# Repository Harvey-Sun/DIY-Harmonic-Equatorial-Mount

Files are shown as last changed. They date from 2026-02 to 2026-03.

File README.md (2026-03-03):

# DIY谐波赤道仪（已通电验证，待实拍测试）

由于我厌倦了EQ3D赤道仪的沉重，我计划用更轻便的谐波赤道仪来替换它，然而市面上的谐波赤道仪价格太贵（与DIY的规格相比），所以这个项目就此诞生，谐波赤道仪能够在不牺牲性能的前提下，提供高精度、便携性和经济性

# 项目描述

自制谐波赤道仪的核心谐波减速器，是基于Leaderdriver拆机二手的工业谐波减速器(也适用于淘宝购买的同规格谐波减速器如“25-100”)
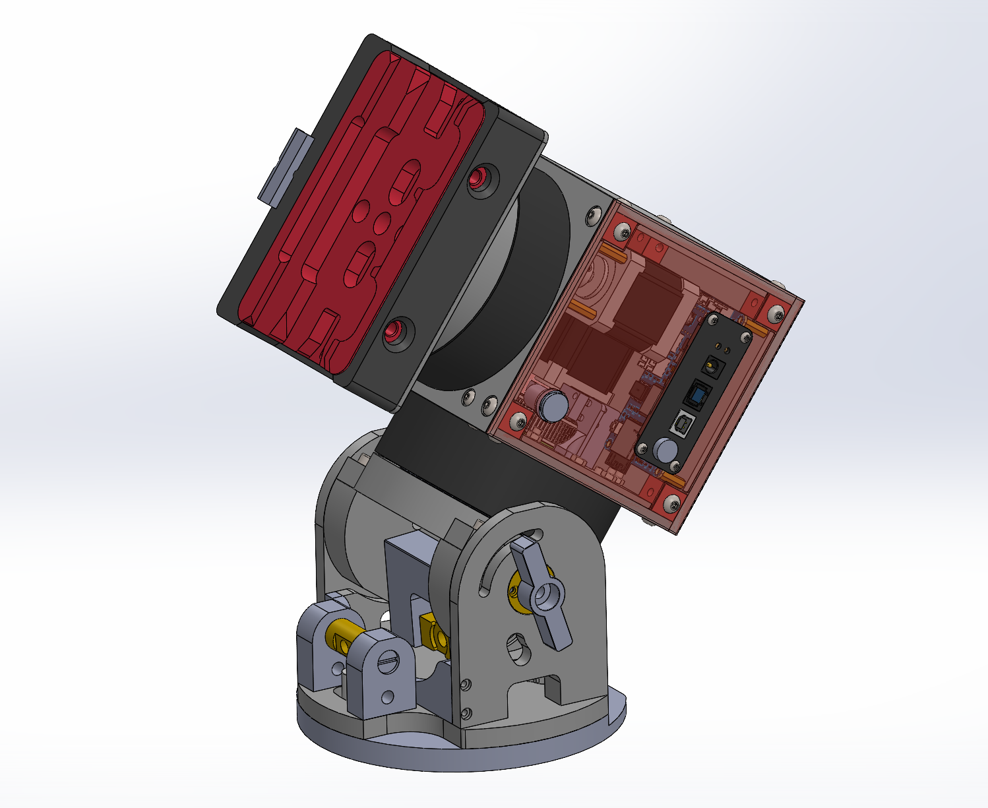
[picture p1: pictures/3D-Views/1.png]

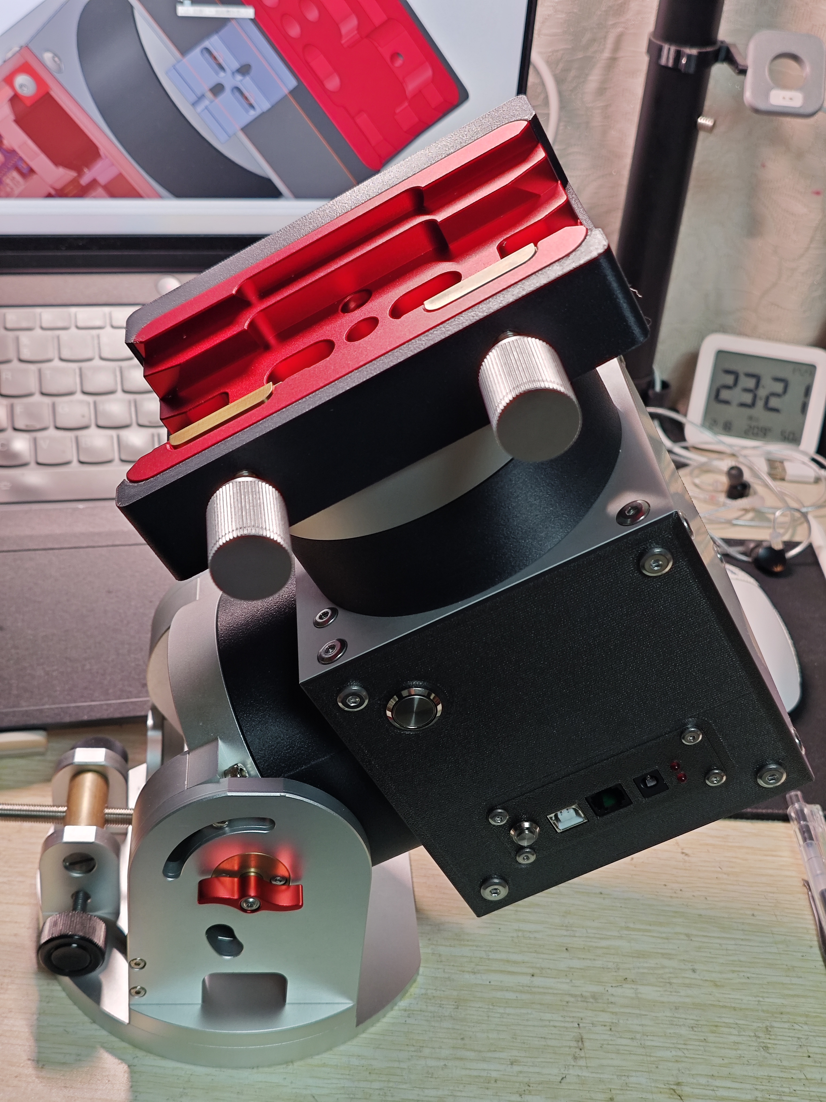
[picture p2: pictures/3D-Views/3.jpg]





该项目旨在解决业余天文设备中的关键问题：
- 成品支架价格高昂
- 缺乏开放性和灵活性
- 复杂性或与个人设置的不兼容

此款DIY谐波赤道仪优势是：
- 🧰**经济实惠**——总造价低于3000元，加工零件价格低于1500元
- 🪶**相对便携**——不含底座重量7.5公斤
- 🏗️**易于搭建**——专为拥有基本工具的创客设计
- 💪**高性能**——精确跟踪（亚角秒级 RMS），无需配重
- ⚠️**关于当前项目状态的说明**⚠️
该项目只完成了通电和简单的goto测试未进行实拍测试

# ✨主要特点
| **特征** | **描述** |
| :----- | :----- |
| 安装类型 | GEM德式赤道仪 |
| 传动类型 | 谐波减速器+皮带传动+42步进电机 |
| 有效载重 | 最大载重30kg(最好需要配重)，无需配重载重为20-25kg |
| 减速器类型 | leaderdrive LHS-25-100-C-III |
| 控制系统 | OnStep/OnStepx |
| 连接类型 | USB-B；WIFI；蓝牙；集成DS3231SN时钟芯片 |
| 硬件功能 | RA轴制动器；RA/DEC轴光电传感器限位；DEC/RA轴光电传感器原点；<br>同时兼容step/dir，spi两种驱动模式(即兼容tmc2209，tmc5160)；12/24v输入 |
| 预计成品 | 2200-2600 RMB |
| 预计重量 | 9.5kg(包含鸠尾槽和纬度座) |

## 🔗 物料清单 (BOM)

请参阅 [BOM.md](BOM.md)

**预计总成本：约2500RMB（含纬度座）**

本项目的主体结构高度依赖定制，主要部件包含两台 25-100 规格的谐波减速器，提供了极高的传动比与扭矩，底座接口可根据个人习惯适配主流的三脚架

*注：价格为近似值，可能因电机供应商、CNC 加工批次和地点而异*

---

## 🔌 电子部分概览

控制系统完全采用定制设计，并围绕紧凑结构构建，它包括：

* **基于 ESP32-WROOM-32E16N 的主控核心**，运行强大的 [OnStep/OnStepX](https://onstep.groups.io/g/main/wiki) 系统
* **搭配 ESP07S 无线连接**，提供高效的无线/有线通讯
* **TMC系列步进电机驱动器**，实现赤经与赤纬轴精确、静音的微步进控制与指向
* **高效电源管理方案**，板载 TPS5450 降压模块和 AMS1117 LDO 稳压芯片，确保高负载下系统电压的纯净与稳定
* 集成 **零位传感器和限位开关** 接口，在运行中保障设备的安全
* 支持通过 Wi-Fi、蓝牙或 USB 路由进行远程控制，无缝对接主流天文摄影软件生态 (N.I.N.A., INDI, ASCOM 等)
* 控制板在 PCB 走线设计上充分考虑了扩展性需求，通过主板驱动器插槽旁的排针跳线 (Jumpers)，您可以轻松地在先进的 **SPI 智能控制模式**和传统的 **STEP/DIR 独立模式**之间进行物理切换(切换后需刷写固件)

* **TMC5160 SPI 模式 (推荐配置) 🚀**
    * **硬件设置**：使用跳线帽闭合 SPI 专用的针脚组，将 ESP32 的 SPI 总线直接连接至 TMC5160 驱动器
    * **系统优势**：彻底告别手动调节电位器，允许 OnStep 固件直接读取和写入寄存器，您可以在 Web 界面或 `Config.h` 中实时配置运行/保持电流、精确设置细分数（Microstepping），并在 StealthChop（极致静音）和 SpreadCycle（高动态扭矩）模式之间智能切换，最大化释放谐波减速器的性能
    * **固件配合**：在 `Config.h` 中将赤经/赤纬驱动模型定义为 `TMC5160_SPI`

* **传统 STEP/DIR 模式 (向下兼容) 🔌**
    * **硬件设置**：断开 SPI 通讯跳线
    * **适用场景**：作为一种可靠的底层回退方案。如果您需要临时替换为普通的 A4988、DRV8825，或者仅使用 TMC 驱动器的 Standalone (独立运行) 模式，此设计提供了极大的硬件容错率和维修便利性
    * **固件配合**：需要在 `Config.h` 中精确填写您通过跳线帽设定的细分值，并**必须手动使用万用表和陶瓷螺丝刀**调节驱动器上的 VREF 电位器来设定电机电流

> 💡 **硬件设计提示**：为确保 SPI 高速通讯时的数据完整性，我们在定制 PCB 上对相关通讯走线进行了严格的间距控制
**警告：在插拔驱动器或更改跳线设置前，请务必完全断开系统主电源（包括 USB 供电），以防瞬间浪涌击穿 TMC5160 或 ESP32 主控**

所有电路板原理图及 PCB Layout（严格把控了安全间距、过孔尺寸和大电流线宽）均使用开源工具设计，您可以在 [https://member.jlc.com/?spm=PCB.Homepage] 订购 PCB或对其进行重新组合以满足您的需求

## 💻 固件配置与刷写

请参阅 [Firmware_Setup.md](https://github.com/LeoJohn233/DIY-Harmonic-Equatorial-Mount/blob/main/software/Firmware_Setup.md) 获取完整的 `Config.h` 参数表及详细引脚映射

谐波赤道仪的主控搭载了 **ESP32-WROOM-32E (16MB)，ESP**，这款大容量核心不仅能轻松运行复杂的 [OnStep / OnStepX](https://onstep.groups.io/g/main/wiki) 固件，还为内置星表、高精度对位模型 (Pointing Model) 以及功能丰富的 Smart Web UI 留出了充足的存储空间

---

## 🛠️ 机械部分组装指南

请参阅 [Assembly.md](Assembly.md)

下图显示了构建 Dual 25 所需的全部机械和电子零件

*(请在此处插入您在“新年首发”时拍摄的组装完成图或零配件合影)*

每个组件都经过精心挑选或设计，以确保高机械精度和易于组装。从 CNC 加工的坚固铝制主体、25-100 谐波减速器，到步进电机和控制器的 3D 打印防护外壳，每一步都经过了严格的测试与指向模型校准。

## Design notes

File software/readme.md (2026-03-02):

# OnStep 优化补丁 (For N.I.N.A. & APP)

## 📌 背景与痛点

在使用 OnStep 驱动谐波赤道仪时，由于谐波减速器不具备物理离合、静摩擦力小且扭矩极大，如果在开机未回零（未建立绝对坐标）的情况下误触指令，或设备两端不平衡，极易导致设备撞台、甚至断电溜车砸毁设备。

同时，在拦截这些危险指令时，如果处理不当，会引发 **LX200 通讯协议底层冲突**，导致以下严重问题：

1. **N.I.N.A. 串口崩溃**：强行返回自定义中文字符串会导致 ASCOM 驱动解析失败 (`Parsing Error`)。
2. **蓝牙极高延迟 (Log Flooding)**：使用 `return` 强行掐断通讯或频繁触发 `CE_PARKED` 错误，会导致底层日志系统疯狂刷屏，撑爆 ESP32 的蓝牙缓存，致使 APP 按键指令严重卡顿。
3. **幽灵跟踪**：GOTO 被拦截后，天文软件的保护机制或预处理逻辑会强行唤醒恒星跟踪。

---

## 🎯 功能特性

本补丁对 `Command.ino`、`OnStep.ino` 及相关初始化逻辑进行了深度优化，实现了完美的“开机防撞锁”、“防溜车机制”与“脱困逻辑”：

* **开机防溜车抱闸**：通电瞬间自动使能电机并进入静止状态，利用电机的保持转矩（Holding Torque）充当电子抱闸，防止严重不平衡时的重力滑落。
* **物理级一键回零**：复用 ST4 导星接口，外接实体按键长按 3 秒即可触发寻找零位（Find Home），并带有硬件级防抖与电机脉冲屏蔽锁。
* **GOTO 拦截伪装**：开机未回零前拦截 GOTO，并向 N.I.N.A. 返回标准 `3` (Standby) 状态，优雅触发弹窗报错，强制关闭误唤醒的跟踪。
* **Tracking 拦截与防堵塞**：未回零前拒绝所有开启跟踪指令，回复标准 `0` (失败)，彻底消除 APP 死等造成的蓝牙高延迟。
* **方向键静默拦截**：未回零或触发限位时，静默锁死对应方向，伪装成无错误 (`CE_NONE`)，实现零延迟、无日志溢出的丝滑手控。
* **Unpark 拦截**：未回零前遵循 LX200 协议拒绝解除停放，防止意外启动。
* **智能限位脱困与单次急停**：撞击限位后仅触发单次急停报警（防刷屏），并仅锁死撞击方向，允许向反方向安全逃离。

---

## 🛠️ 代码修改指南

### 1. 开机自动使能电机防止“溜车”滑落 (修改初始化逻辑)

**定位**: 搜索 OnStep 初始化或开机默认跟踪状态配置的代码段（通常在 `setup()` 尾部或处理 `TrackingNone` 初始化的逻辑中）。
**修改逻辑**: 针对谐波减速器断电易滑落的物理特性，在开机瞬间强制物理激活步进电机驱动器。

```cpp
    // --- [修改开始] 开机防滑落抱死 ---
    // 1. 将状态设置为“TrackingNone”
    // 作用：系统进入工作状态（Active），但不发送步进脉冲，电机保持绝对静止
    trackingState = TrackingNone;
    
    // 2. 物理激活驱动器 
    // 作用：拉低 EN 引脚，让电机通电产生保持转矩（Holding Torque），充当电子抱闸
    enableStepperDrivers();
    // --- [修改结束] ---
```

### 2. 复用 ST4 接口实现物理“一键回零” (修改 `ST4` 逻辑)

**定位**: 搜索 `void ST4()` 函数内部，定位到 `// standard hand control` 下方区域。
**修改逻辑**: 巧妙利用闲置的 ST4 导星接口，外接物理按键（同时短接 East 和 West 引脚至 GND）。加入 `homingLockout` 防抖锁。

```cpp
  // standard hand control
  const long Shed_ms=4000;
  const long AltMode_ms=2000;

  // =================================================================
  // [新增] 长按 3 秒立即触发回零，附带按键屏蔽锁，保护电机脉冲
  // =================================================================
  static bool homingLockout = false; // 屏蔽锁状态标志

  // 1. 如果锁是开启的，说明已经触发了回原点，此时检测是否松手
  if (homingLockout) {
    // 只要有任意一个按键还按着，就会直接 return 退出，彻底屏蔽干扰！
    if (!st4e.isDown() && !st4w.isDown() && !st4n.isDown() && !st4s.isDown()) {
      homingLockout = false; 
    }
    return; // 拦截点，保护回原点过程不被打断
  }

  // 2. 长按检测逻辑
  if ((trackingState != TrackingMoveTo) && (!waitingHome)) {
    // 检测是否同时按下了东键(E)和西键(W)
    if (st4e.isDown() && st4w.isDown()) {
      
      // 如果按下的时间达到了 3000 毫秒（3秒）
      if ((st4e.timeDown() > 3000) && (st4w.timeDown() > 3000)) {
        homingLockout = true; // 第一步：立刻上锁，忽略接下来的所有按键状态
        soundBeep();          // 蜂鸣器滴一声，提示用户
        
        // 停止一切当前的追踪和导星动作
        stopGuideAxis1();
        stopGuideAxis2();
        stopSlewingAndTracking(SS_ALL_FAST);
        
        // 第二步：立刻触发回原点，不需要等松手
        goHome(true); 
        return; 
      }
      
      // 如果按下了，但是还没满 3 秒：
      // 需要阻止原本的 AltMode 或常规导星逻辑触发，叫停轴 1 并立刻返回等待计时
      stopGuideAxis1(); 
      return; 
    }
  }
  // =================================================================
```

### 3. 拦截 GOTO 并强制关闭跟踪 (修改 `Command.ino`)

**定位**: 搜索 `if (command[1] == 'S' && parameter[0] == 0)` (处理 `:MS#` 指令处)
**修改逻辑**: 伪装成待机状态 (`3`)，优雅弹窗，关闭跟踪，且不产生报错日志。

```cpp
      // :MS#       Goto the Target Object
      if (command[1] == 'S' && parameter[0] == 0)  {
        
        // --- [新增] 拦截 GOTO，伪装成 Standby (待机) 状态 ---
        if (!systemHasHomed) {
            reply[0] = '3'; // 返回 3，代表 controller in standby
            reply[1] = 0;
            boolReply = false;
            supress_frame = true;
            
            // 骗过 OnStep 底层日志系统，防止蓝牙卡顿
            commandError = CE_NONE; 

            // 顺手强制关闭可能被 APP 提前唤醒的跟踪功能
            trackingState = TrackingNone; 

        } else {
            // ... [保留原本的 GOTO 逻辑] ...
            newTargetRA=origTargetRA; newTargetDec=origTargetDec;
#if TELESCOPE_COORDINATES == TOPOCENTRIC
            topocentricToObservedPlace(&newTargetRA,&newTargetDec);
#endif
            CommandErrors e=goToEqu(newTargetRA,newTargetDec);
            if (e >= CE_GOTO_ERR_BELOW_HORIZON && e <= CE_GOTO_ERR_UNSPECIFIED) reply[0]=(char)(e-CE_GOTO_ERR_BELOW_HORIZON)+'1';
            if (e == CE_NONE) reply[0]='0';
            reply[1]=0;
            boolReply=false;
            supress_frame=true;
            commandError=e;
        }
      } else
```

### 4. 规范拦截开启跟踪消除闲置高延迟 (修改 `Command.ino`)

**定位**: 搜索 `if (command[0] == 'T'` 下方的 `if (command[1] == 'e') {` (即 `:Te#` 指令)
**修改逻辑**: 强制规范回复 `0`，防止 APP 死等导致蓝牙崩溃。

```cpp
        // :Te#       Tracking enable
        if (command[1] == 'e') {
          
          // --- [新增] 必须标准回复 0，否则 APP 死等导致蓝牙崩溃！ ---
          if (!systemHasHomed) {
              reply[0] = '0'; // 明确告诉 APP 被拒绝了
              reply[1] = 0; 
              boolReply = false; 
              supress_frame = true; 
              commandError = CE_NONE; // 保持静默，不刷日志
              return; 
          }
          // --------------------------------------------------------

          if (isParked()) commandError=CE_PARKED; else
          // ... [保留原有 trackingState 逻辑] ...
```

### 5. 拦截手动方向键实现零延迟静默锁 (修改 `Command.ino`)

**定位**: 搜索 `:Me#` 或 `Move Telescope East or West`
**修改逻辑**: 剥离 `return`，使用 `CE_NONE` 欺骗日志系统，实现静默锁死。

```cpp
      // :Me# :Mw#  Move Telescope East or West at current guide rate
      if ((command[1] == 'e' || command[1] == 'w') && parameter[0] == 0) {
        
        // --- [修改] 没回零，或者按了东且东面锁死，或者按了西且西面锁死 ---
        if (!systemHasHomed || (command[1] == 'e' && Axis1_LimitLock == 1) || (command[1] == 'w' && Axis1_LimitLock == -1)) {
            boolReply = false;       // 告诉底层：不用返回字符
            commandError = CE_NONE;  // 伪装成无错误！
        } else {
            commandError=startGuideAxis1(command[1],currentGuideRate,GUIDE_TIME_LIMIT*1000,false);
            boolReply=false;
        }
      } else
      
      // :Mn# :Ms#  Move Telescope North or South at current guide rate
      if ((command[1] == 'n' || command[1] == 's') && parameter[0] == 0) {
        
        // --- [修改] 没回零，或者按了北且北面锁死，或者按了南且南面锁死 ---
        if (!systemHasHomed || (command[1] == 'n' && Axis2_LimitLock == 1) || (command[1] == 's' && Axis2_LimitLock == -1)) {
            boolReply = false;       
            commandError = CE_NONE;  
        } else {
            commandError=startGuideAxis2(command[1],currentGuideRate,GUIDE_TIME_LIMIT*1000,false);
            boolReply=false;
        }
      } else
```

### 6. 优化智能脱困与单次急停防刷屏 (修改 `OnStep.ino`)

**定位**: 搜索 `loop2()` 中限位判断代码。
**修改逻辑**: 移除易导致意外锁死的坐标推断逻辑，增加单次报错锁防刷屏。

```cpp
        // =========================================================
        // 恢复纯粹的撞击方向锁死逻辑
        // =========================================================
        if (Axis1_LimitLock == 0 && currentMotionDir1 != 0) {
            Axis1_LimitLock = currentMotionDir1;
        }
        if (Axis2_LimitLock == 0 && currentMotionDir2 != 0) {
            Axis2_LimitLock = currentMotionDir2;
        }

        // =========================================================
        // 执行急停 (带有单次触发锁)
        // =========================================================
        if (!isEscaping) {
            // --- [核心修改] 加一把单次触发锁，防止刷屏撑爆蓝牙 ---
            if (generalError != ERR_LIMIT_SENSE) {
                generalError = ERR_LIMIT_SENSE;
                stopGuideAxis1(); 
                stopGuideAxis2();
                stopSlewingAndTracking(SS_LIMIT_HARD);
            }
        }
```

---

## 💡 总结与建议

经过上述修改，基于 OnStep 的谐波赤道仪如同加上了“物理级”的安全外骨骼。从开机通电的瞬间到未回零前的任何误操作，都被死死按在安全的边界内，且完美兼顾了 ASCOM 驱动和 LX200 协议的底层脾气。建议搭配 N.I.N.A. 等上位机软件使用时，养成开机首选 **Find Home** 的良好习惯，享受丝滑且安全的星空探索。

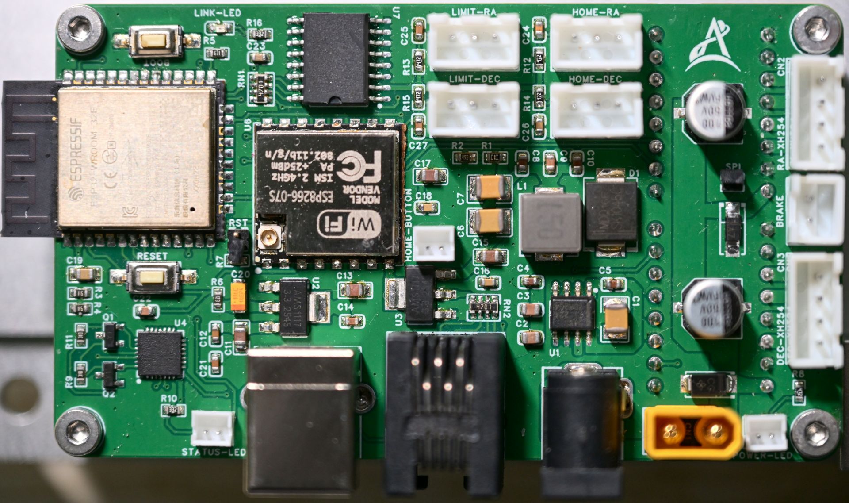
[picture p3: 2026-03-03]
pictures/pcb/PCB-1.jpg

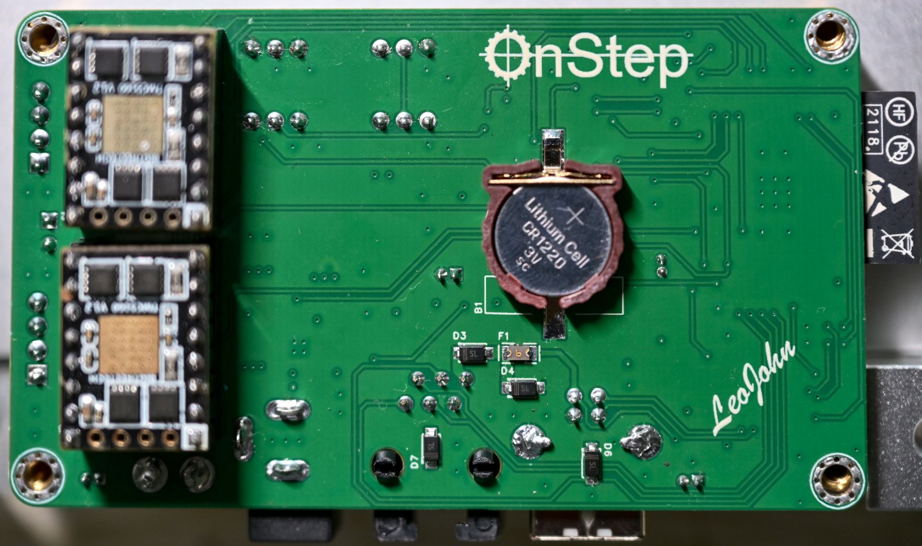
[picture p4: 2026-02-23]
pictures/pcb/PCB-2.jpg

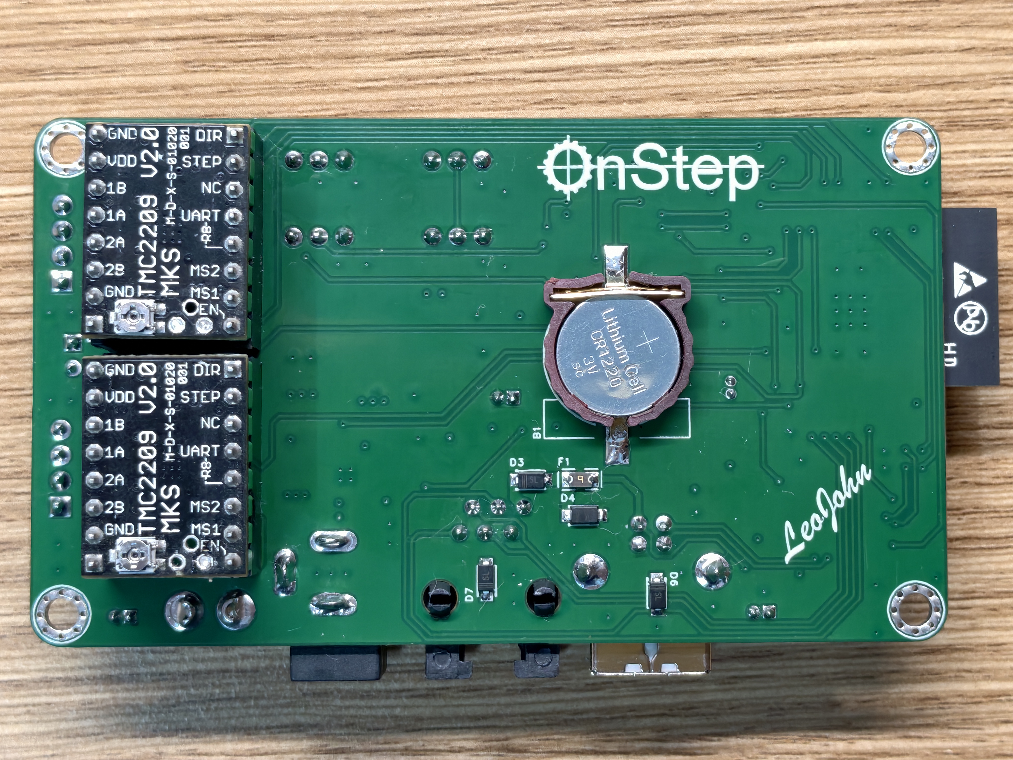
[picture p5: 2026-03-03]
pictures/pcb/PCB-3.jpg

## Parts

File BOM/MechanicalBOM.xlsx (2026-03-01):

名称 | 规格 | 数量
塞打螺栓 | 8*10*M6 | 2
塞打螺栓 | 8*8*M6 | 2
一字塞打螺栓 | 8*10*M6 | 2
12.9级杯头螺丝 | M5*18 | 8
304不锈钢内螺纹圆柱销 | Φ12*25*M6 | 1
小微型推力球平面轴承 | F8-14M 尺寸8*14*4 | 2
304不锈钢一字塞打螺丝 | M8*4*M6 | 2
圆切边法兰铜合金无油衬套黄铜铜套 | 8-15(27*4/8*12*15)-圆光 | 2
12.9级杯头螺丝 | M5*14 | 2
薄头内六角螺丝钉DIN7984 | M3*4 | 4
铜垫片 | M8*12*0.5 | 4
铜垫片 | M5*9*0.5 | 2
不锈钢超薄垫片 | 8*12*0.2 | 4
12.9级薄头内六角螺丝DIN7984 | M4*16 | 8
12.9级薄头内六角螺丝DIN7984 | M4*12 | 4
12.9级高强度镀镍薄头内六角螺丝 | M6*12 | 4

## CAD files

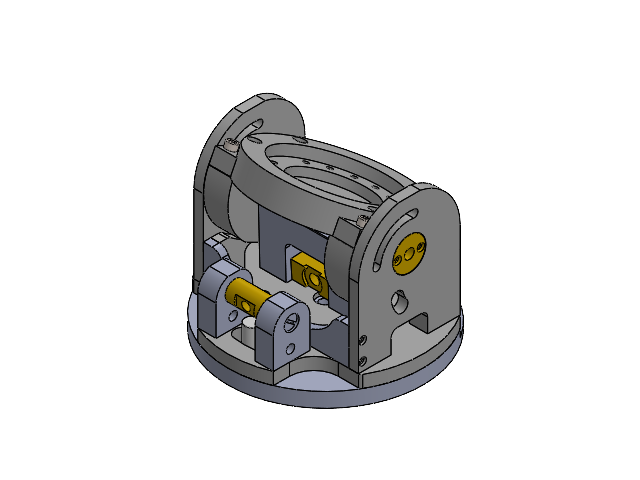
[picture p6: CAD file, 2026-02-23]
hardware/SW2024/纬度座/纬度座.SLDASM
固定盘
旋转盘
支撑臂A
RA法兰盘
连接轴A
连接轴B
法兰铜套 x 2
支撑臂B
圆柱销
俯仰调节A
俯仰调节B
铜棒A
连杆
铝合金推块
铝合金定位凸台
支撑板
hexagon socket head cap screws gb x 8
8-8-M6 x 2
8-10-M6 x 2
8-10-M6一字 x 2

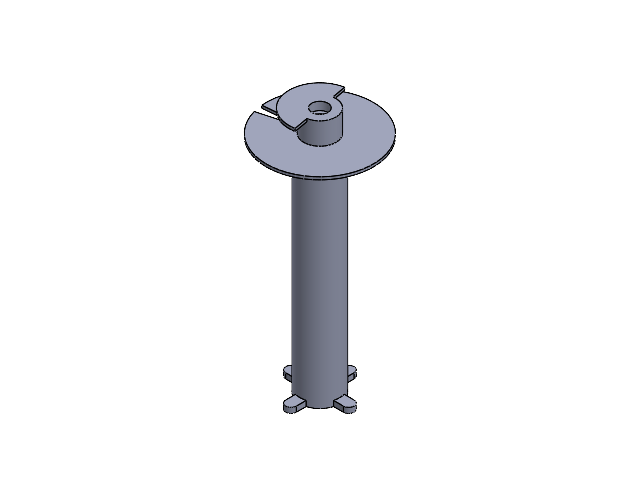
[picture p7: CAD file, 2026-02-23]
hardware/SW2024/赤道仪本体/部分零件组合/DEC轴双层.SLDASM
DEC轴
340度限位盘 - DEC
零件1^DEC轴双层

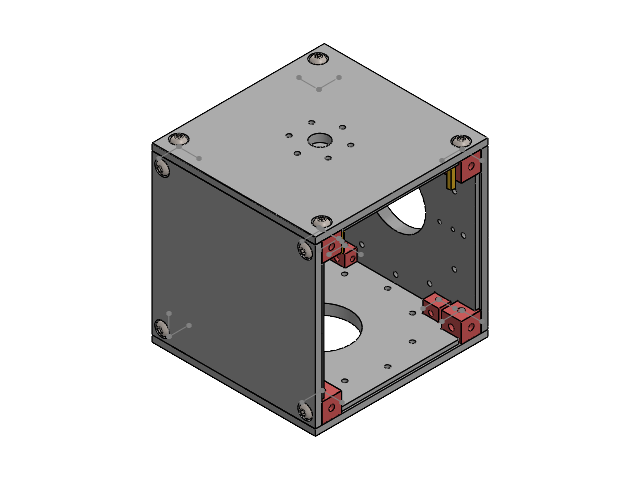
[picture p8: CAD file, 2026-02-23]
hardware/SW2024/赤道仪本体/部分零件组合/25-100外壳.SLDASM
赤纬轴固定板
赤经轴固定板
固定板A
固定板B
15mm方形连接件 x 8
12mm方形连接件 x 2
hexagon socket button head screws gb x 20
主板铜柱 x 4

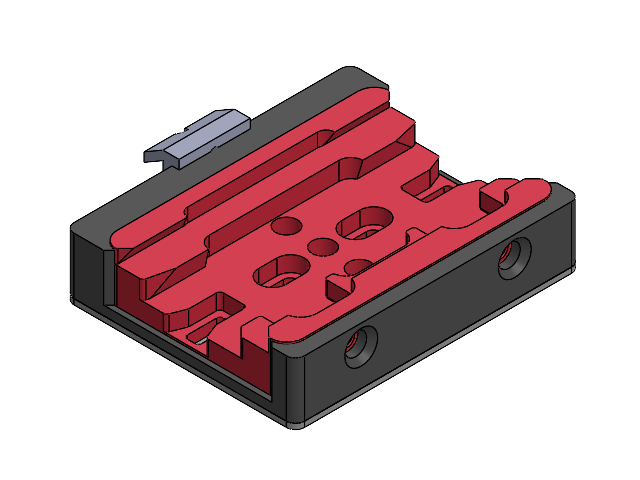
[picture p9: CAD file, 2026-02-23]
hardware/SW2024/赤道仪本体/部分零件组合/鸠尾槽外壳+底板.SLDASM
鸠尾槽外壳
宽型鸠尾槽-2024
鸠尾槽外壳支撑铝板^鸠尾槽外壳+底板
桥式鸠尾槽

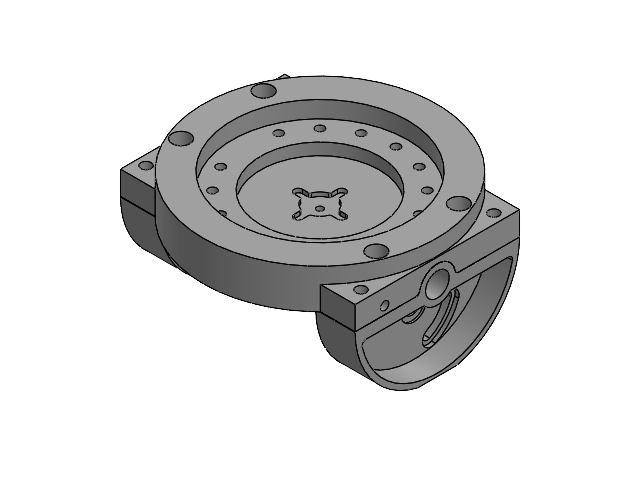
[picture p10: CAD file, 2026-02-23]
hardware/SW2024/纬度座/RA轴连接件.SLDASM
RA法兰盘
连接轴A
连接轴B

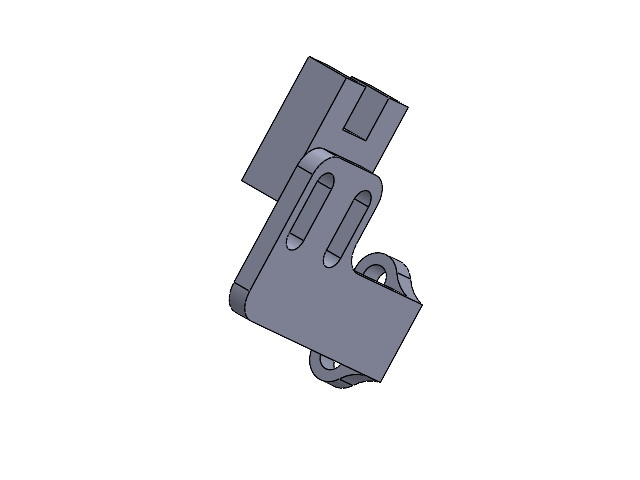
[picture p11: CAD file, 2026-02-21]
hardware/SW2024/赤道仪本体/部分零件组合/原点传感器+固定座.SLDASM
光电传感器
光电传感器固定座B

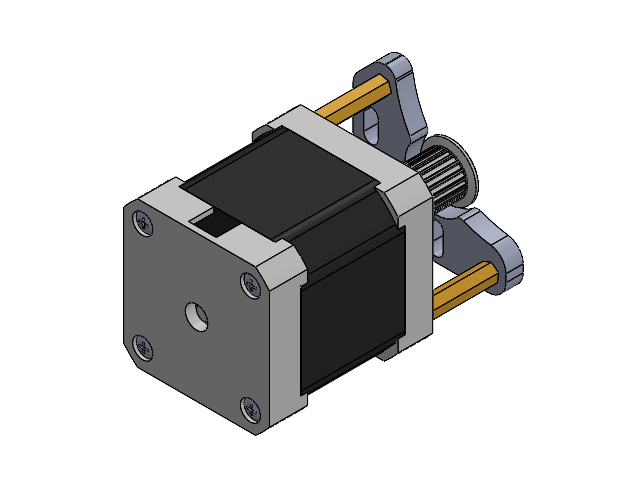
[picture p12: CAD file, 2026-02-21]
hardware/SW2024/赤道仪本体/部分零件组合/DEC轴电机+支架.SLDASM
42CM06
铜柱 x 3
电机支架
M4x0.7X5mm - flat-tip Set screw x 2
2GT-20T-10

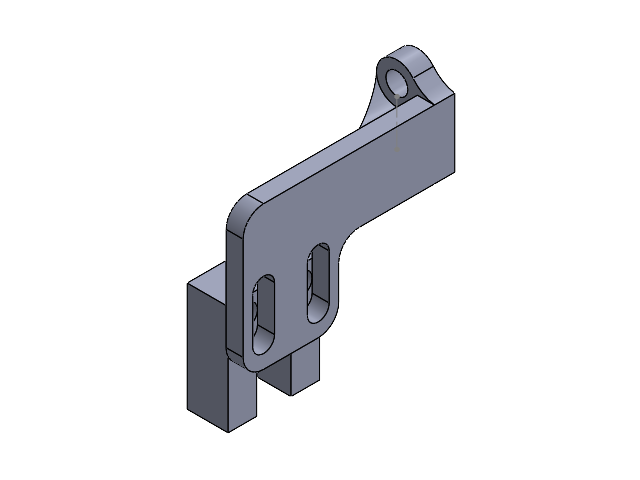
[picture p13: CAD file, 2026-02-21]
hardware/SW2024/赤道仪本体/部分零件组合/限位传感器+固定座.SLDASM
光电传感器固定座A
光电传感器

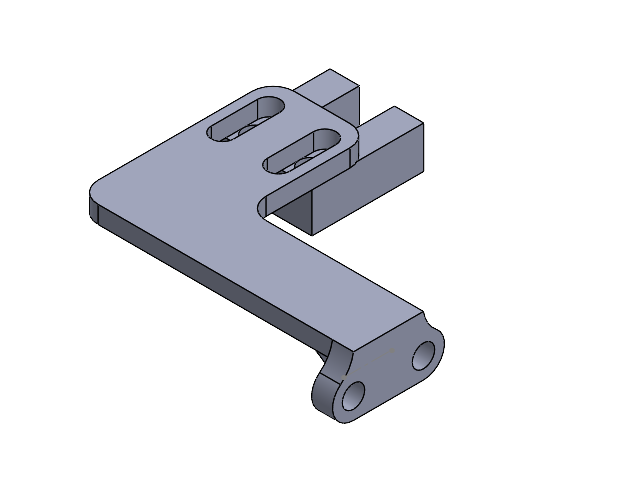
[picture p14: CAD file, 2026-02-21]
hardware/SW2024/赤道仪本体/部分零件组合/限位传感器+增高固定座.SLDASM
光电传感器
光电传感器固定座B - 增高

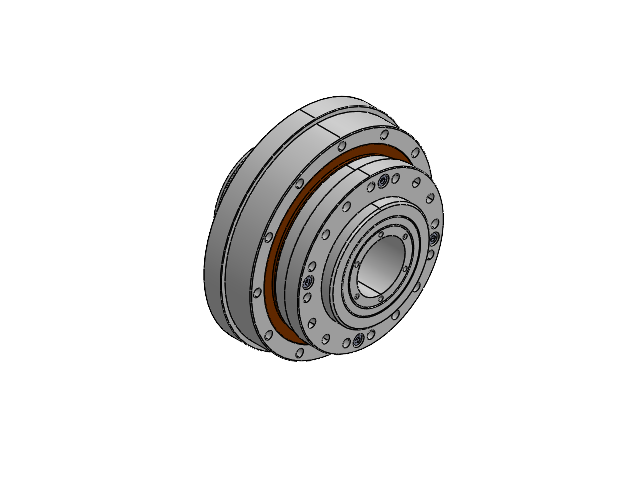
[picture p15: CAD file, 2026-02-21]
hardware/SW2024/赤道仪本体/部分零件组合/谐波+惰轮.SLDASM
RZC-25G______+____
RZC-25______
LHSG-25-XXX-P03-III-S0
DB-25G-III-S0
LHS-25-P08L-III-S0
LHS-25-P06L-III-S0
LHS-25-XXX-P01-TT
LHS-25-P04A-1
LHS-25-P02-III
hexagon socket button head screws gb_GB_SOCKET_TYPE7 M3X6-N x 5
socket head cap screw_din_________________M3 x 16 x 4
LHS-25-P04A-2
LHS-25-P07(L)-III_1
GV38_1
countersunk flat head cross recess screw_din_ISO 7046-1 - M2 x 4 - Z --- 4N x 8
deep groove ball bearings gb_Rolling bearings 61808 GB 276-94 x 2
84945 TCY
15Z-38475_1 x 2
增高法兰
内径12外径24带边轴承
2GT-80T-10mm

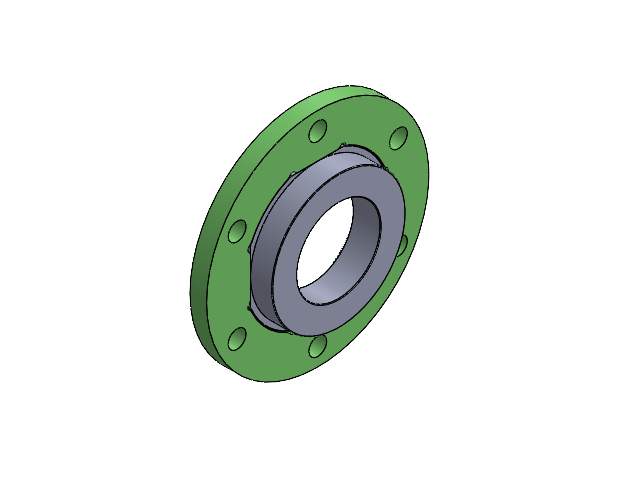
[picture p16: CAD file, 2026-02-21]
hardware/SW2024/赤道仪本体/部分零件组合/轴承托盘.SLDASM
增高法兰
内径12外径24带边轴承

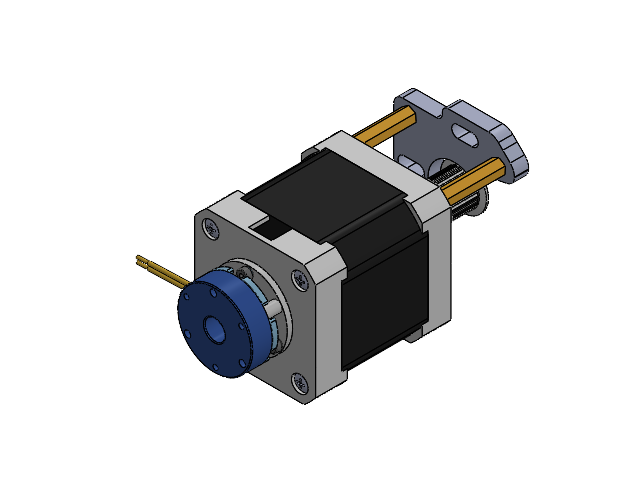
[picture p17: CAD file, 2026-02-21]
hardware/SW2024/赤道仪本体/部分零件组合/RA轴电机+支架.SLDASM
______-2_2_Default
______-2_2_Default-0
____-2_2_Default
____-2_2_Default-1 x 4
__-2_2_Default
电机支架
铜柱 x 3
SWB-003
M4x0.7X5mm - flat-tip Set screw x 2
2GT-20T-10

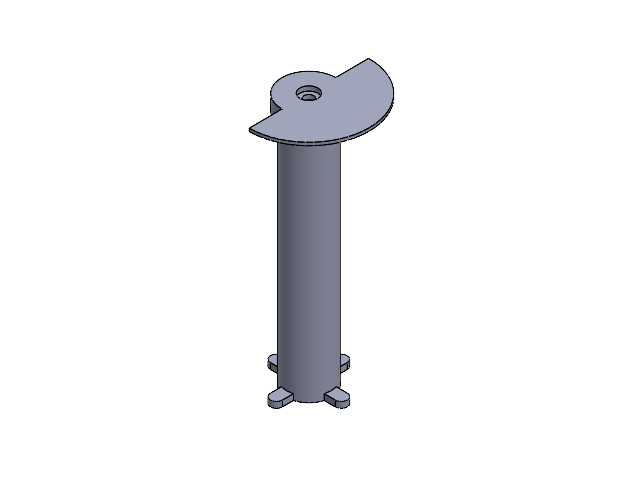
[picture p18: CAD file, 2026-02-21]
hardware/SW2024/赤道仪本体/部分零件组合/RA轴+180度.SLDASM
RA轴
180度限位盘

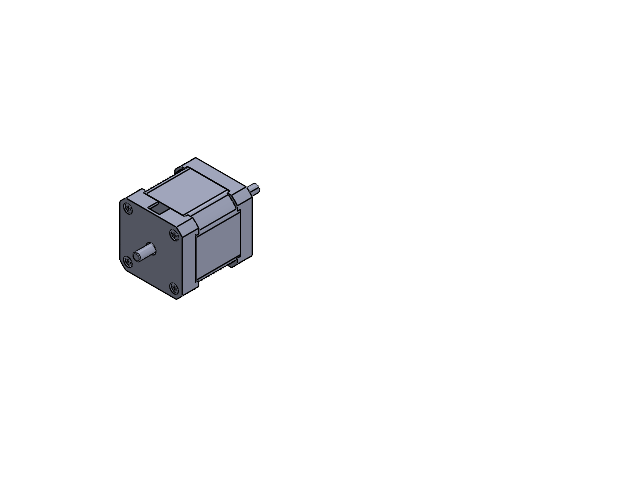
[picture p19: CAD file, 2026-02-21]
hardware/SW2024/赤道仪本体/42CM06-SZ.SLDASM
______-2_2_Default
______-2_2_Default-0
____-2_2_Default
____-2_2_Default-1 x 4
__-2_2_Default

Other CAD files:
hardware/SW2024/赤道仪本体/2GT-20T/GT2 Timing Pulley 20T 10mm - Hole_5mm.SLDASM
hardware/SW2024/赤道仪本体/25-100谐波减速器/________RZC-25G.SLDASM
hardware/SW2024/赤道仪本体/SWB-003 _1_.SLDASM
hardware/SW2024/赤道仪本体/2GT-20T-10mm宽通孔5mm.SLDASM
hardware/STEP/纬度座/RA法兰盘.STEP
hardware/STEP/纬度座/俯仰调节A.STEP
hardware/STEP/纬度座/俯仰调节B.STEP
hardware/STEP/纬度座/内圈凸出轴承.STEP
hardware/STEP/纬度座/固定盘.STEP
hardware/STEP/纬度座/支撑板.STEP
hardware/STEP/纬度座/支撑板打孔模具A.STEP
hardware/STEP/纬度座/支撑板打孔模具B.STEP
hardware/STEP/纬度座/支撑臂A.STEP
hardware/STEP/纬度座/支撑臂B.STEP
hardware/STEP/纬度座/旋转盘.STEP
hardware/STEP/纬度座/转轴A打孔模具.STEP
hardware/STEP/纬度座/转轴B打孔模具.STEP
hardware/STEP/纬度座/连接轴A.STEP
hardware/STEP/纬度座/连接轴B.STEP
hardware/STEP/纬度座/连杆.STEP
hardware/STEP/赤道仪本体/180度限位盘.STEP
hardware/STEP/赤道仪本体/340度限位盘 - DEC.STEP
hardware/STEP/赤道仪本体/DEC法兰盘.STEP
hardware/STEP/赤道仪本体/DEC轴340度限位盘 -.STEP
hardware/STEP/赤道仪本体/DEC轴原点遮光盘.STEP
hardware/STEP/赤道仪本体/RA轴.STEP
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

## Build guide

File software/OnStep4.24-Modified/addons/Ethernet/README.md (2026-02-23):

# OnStepEthernetServer

This is the Arduino webserver for OnStep.  It provides Ethernet (IP) access to connect to OnStep via command channel and/or website.  This works with Sky Safari (tablets/phones,) my OnStep Android App, and my ASCOM driver (PC.)

For my testing I used an Arduino M0 and Arduino Ethernet Shield R3 (W5100.)  Other configurations are untested but Arduino's with ARM MCU's and similar Ethernet Shields should generally work.  There are reports of the Arduino Ethernet Shield V2 not working with the M0 so aviod that!

Use the Arduino IDE's "Tools->Boards->Boards Manager" menu to add ARM device support.

This source code is inside your OnStep folder under the "src/Ethernet" subdirectory.

Open the Ethernet.ino file inside this folder.  Find the "Config.h" tab and make any changes as required for your setup.  Upload.

Once the firmware is on the device simply connect the serial interface lines to OnStep's Serial1 port similar to how a Bluetooth module would be connected.

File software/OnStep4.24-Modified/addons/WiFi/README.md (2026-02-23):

# OnStep WiFi Server
This is the ESP8266 webserver for OnStep.
It enables OnStep to be controlled over WiFi (IP). This access can be over a command channel
and/or website.
This server is known to work from personal computers (using a browser), phones and tablets,
(using the Android OnStep App), Sky Safari, and my ASCOM driver (PC.)

# Installing the ESP8266 Platform
Before you can flash the firmware on your ESP8266 device, you need to install the ESP8266
platform for the Arduino IDE.

Under Preferences add this line in the additional "Boards Manager" area:
  http://arduino.esp8266.com/stable/package_esp8266com_index.json

Then from the "Tools, Boards, Boards Manager" menu select and install the ESP8266 add-on.

# Flashing The WiFi Server
The exact flashing procedure depends on which ESP8826 device you will be using.

In the Arduino IDE, pick your device from "Tools, Boards". 

For a WeMos D1 Mini or NodeMCU, select the device from the list.
For an ESP-01, select "Generic 8266 Module".

For devices with a USB port (WeMos D1 Mini, NodeMCU), you can connect directly using the USB connector.
For an ESP-01 module, its pins should be in a certain configuration:

Pin CHPD/EN must be HIGH (connected to 3.3V)
Pin GPIO0 must be LOW (connected to GND).

You can buy an inexpensive adapter or board that help with flashing the ESP01 from eBay, Amazon and other sources.

For the ESP-01, use the following parameters under Tools:

- Board: "Generic ESP8266 Module"
- Flash Mode: "DIO"
- Erase Flash: "Sketch + WiFi Settings"
- Flash Size: "1M (64K SPIFFS)" (Most ESP01 have 1M, older ones have 512K)
- Flash Frequency: "40MHz"
- CPU Frequency: "80 MHz"
- Reset Method: "ck"
- Upload Speed: "115200"
- Debug Port: "Disabled"
- Debug Level: "None"

The source code is inside the OnStep folder under the "addons/WiFi-Bluetooth" subdirectory.

Open the WiFi-Bluetooth.ino file inside this folder. Check the "Config.h" file for information
about serial port wiring and to configure before uploading.  Once this is done upload to the ESP8266.

# Wiring
If you are using a pre-wired board (e.g. MiniPCB, MaxPCB), you don't need to worry about wiring, since
it is all done for you.

If you are not using a pre-wired board, you have to connect your ESP8266 to certain pins for your
microcontroller.  Basically, the TX on the ESP8266 should be connected on Serial1's RX for the
microcontroller, and RX on the ESP8266 should be connected to TX on Serial1 for the microcontroller.

Note that Serial1 may be remapped in the HAL for your microcontroller, for example on STM32, PA10/TX
and PA11/RX are used, and they are designated Serial3. If you are using a HAL that is tested and
verified working, you don't need to worry about this part. 

You also need to make the CHPD/EN pin high by connecting it to 3.3V, otherwise, your ESP-01 would
not turn on. 

# Power
These modules require more power than the 3.3v regulator on a Mega2560 can supply so the WeMos or
NodeMCU with on-board regulator can be handy.  The Teensy3.2's 3.3v regulator will run an ESP-01.
This should work with OnStep on any Platform (Mega2560, Teensy3.2, and Launchpad TM4C.)  OnStep running
on the Teensy3.2 is well tested with it.

# Starting Up
The WiFi server will only start WiFi if it was able to connect to OnStep via Serial1 and find it working.
Otherwise, you will not see the "ONSTEP" SSID.

You can replace DEBUG_OFF in Config.h with DEBUG_ON to change this behavior, and allow for resetting
the configuration on the ESP.

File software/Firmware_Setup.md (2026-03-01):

谐波赤道仪的主控使用了 **ESP32-WROOM-32E16N (16MB 闪存版)**,这款大容量核心能轻松运行复杂的 [OnStep / OnStepX](https://onstep.groups.io/g/main/wiki) 固件

## ⚙️ 编译环境与主板设置 (至关重要)

由于我们使用的是 16MB 版本的 ESP32，**不要使用默认的 4MB 编译设置**，否则将导致固件编译失败或浪费大量存储空间。以下是基于 Arduino IDE 的官方推荐配置流程（同样适用于 PlatformIO 用户修改 `platformio.ini`）：

1. **准备环境**：下载最新版 Arduino IDE，并在“首选项”中添加 ESP32 开发板管理器网址，安装最新版 ESP32 支持包（建议 2.0.0 版本以获得最佳兼容性）
2. **选择主板**：在 `工具 (Tools)` -> `开发板 (Board)` 中选择 **ESP32 Dev Module**。
3. **关键参数配置**（严格按照以下设置）：
   * **Flash Size (闪存大小)**: 选择 `16MB (128Mb)`
   * **Partition Scheme (分区方案)**: 选择针对 OnStep 优化的方案，例如 `16M Flash (3MB APP/9.9MB FATFS)` 或 `Huge APP`。这确保了有足够的空间存放 OnStep 庞大的核心代码
   * **PSRAM**: 如果您的模块带 PSRAM 请设为 `Enabled`，标准 32E 请保持 `Disabled`。
   * **Upload Speed (上传速度)**: `921600`（如遇不稳可降至 `460800`）。

## 📝 Config.h 核心参数适配

在正式刷写前，您需要在 OnStep 源码中修改 `Config.h` 以精准适配硬件，参考模板为`Config-5160.h`和`Config-2209.h`
**💡：若您复刻的机械与结构设计（包括电机和谐波减速器规格）与本项目完全一样，相关参数就可以直接复制刷写**

* **引脚映射 (Pinmap)**：找到并启用与本定制 PCB 匹配的引脚定义方案，确保通讯走线、步进脉冲 (STEP/DIR) 以及限位开关等接口映射正确
* **每度步数配置 (Steps per Degree)**：
    * 核心计算公式：`(电机每圈物理步数 × 细分数 × 总减速比) / 360`，以搭配标准的 1.8° 步进电机（每圈 200 步）和 1:100 的 25 规格谐波减速器为例，具体数值取决于您使用的驱动器模式
* **模式 A：TMC5160 SPI 智能模式 (推荐 🚀)**：
    * **驱动器型号**：将赤经 (RA) 和赤纬 (Dec) 轴严格定义为 `TMC5160_SPI`。
    * **细分设置**：建议设为 **64** 或 **128**（TMC 会在底层自动插值到 256 微步，保证星流追踪的极致平滑）。
    * **参数抄作业**：若使用 64 细分，计算为 `(200 × 64 × 100) / 360 ≈ 3555.556`。请将 `3555.556` 填入 `AXIS1_STEPS_PER_DEGREE` 和 `AXIS2_STEPS_PER_DEGREE`
* **模式 B：传统 STEP/DIR 模式 (向下兼容 🔌)**：
    * **驱动器型号**：若通过跳线断开 SPI 并使用 A4988、DRV8825 或独立模式的 TMC，请将驱动模型修改为对应的型号（如 `A4988` 或 `GENERIC`）
    * **细分严格匹配**：⚠️ 固件中的 `AXIS_MICROSTEPS` **必须严格等于**主板跳线帽设定的物理细分值，固件无法在此模式下动态更改细分
    * **参数抄作业**：若物理跳线设为 32 细分，计算为 `(200 × 32 × 100) / 360 ≈ 1777.778`，请将其填入对应的步数参数中
    * **⚡ 电流设置 (手动调节)**： 在传统模式下，OnStep 无法通过软件控流，您必须在主板通电的状态下，使用万用表测量，并用陶瓷十字螺丝刀极其缓慢地旋转驱动器模块上的电位器来设定 VREF 参考电压。**操作时请务必小心防短路！**

## 🚀 刷写固件与上传 Web UI

OnStep 在 ESP32 平台上的完整安装包含**两个独立步骤**（固件 + 文件系统），缺一不可：

**第一步：上传 OnStep 核心固件**
1. 使用优质的数据线连接主控板。系统通讯依赖板载的 CP2102N 芯片，请确保已安装 Silicon Labs 官方驱动
2. 在 IDE 中选择对应的 COM 端口，点击“上传 (Upload)”。
   * *注：如果终端出现 `Connecting...` 超时，请按住 PCB 上的 `BOOT` 按钮直到进度条出现。*

**第二步：上传 Smart Web Sever**
通过 Wi-Fi 控制OnStep的行为依赖于存储在ESP07S闪存中的网页文件，由于PCB的紧凑设计，并没有给ESP07S留出单独的刷写通道，故需通过将ESP32作为转发桥梁来刷写固件
* *注：在刷写ESP32时需要将`Config.h`中的`#define SERIAL_B_ESP_FLASHING`功能打开，并将PCB上对应的RST针脚进行跳线帽连接
### 📡 ESP32 透传刷写 ESP07s (SmartWebServer) 指南

请严格按照以下顺序执行，错一步都会导致刷写失败，若复刻的结构设计完全一样，参数就可以直接复制刷写

### 🛠️ 第一阶段：准备工作

为了使用命令行工具进行刷写，我们不能直接上传源码，必须预先生成 `.bin` 格式的固件文件，并准备好对应的刷写工具。

### 1. 准备 WiFi 固件文件 (`.bin`)

1. 在 Arduino IDE 中打开 ESP8266 WiFi (SmartWebServer) 源码
2. 在 **工具 (Tools) -> 开发板 (Board)** 中，选择 **`LOLIN(WeMos) D1 R2 & mini`**
3. 点击菜单栏：**项目 (Sketch) -> 导出已编译的二进制文件 (Export Compiled Binary)**
4. 去源码文件夹找到刚刚生成的 `.bin` 文件（选择那个文件名最短的，比如 `SmartWebServer.bin`）。
5. 将它复制到 `D 盘` 根目录，并改个简单的名字，比如 `wifi.bin`

### 2. 准备刷写工具 (`esptool`)

你需要 Python 环境下的 `esptool.py` 或者编译好的独立程序 `esptool.exe`

* **如果你装了 Python**：打开 CMD 命令提示符，输入 `pip install esptool` 即可完成安装
* **如果你没有装 Python**：去 Arduino 的安装目录里搜索 `esptool.exe`，把它复制到 `D 盘` 根目录备用

---

### 🚀 第二阶段：操作流程

### 第一步：建立透传通道

1. 将包含 ESP32 的主控板通过 USB 连接至电脑
2. 打开 Arduino 的 **串口监视器 (Serial Monitor)**
3. 在发送框输入：`:ESPFLASH#` 并点击发送
4. **关键检查**：此时 OnStep 会根据预先定义的引脚，自动拉低 IO26 (WiFi IO0)，然后拉低再拉高 IO2 (WiFi RST)。如果这一步成功，ESP07s 现在应该已经处于“等待刷写”的状态
5. 🛑 **关闭串口监视器！** (这一步极其重要，必须释放 COM 口供下一步的 esptool 使用)

### 第二步：执行“无复位”刷写指令

打开电脑的 CMD (命令提示符)，根据你准备的工具输入以下命令（假设文件在 D 盘，端口是 `COM7`，请根据实际情况修改）：

**选项 A：使用 `esptool.exe` (Windows 独立程序)**
先输入 `D:` 回车（切换到 D 盘），然后执行：
```bash
esptool.exe -p COM7 -b 115200 --before no_reset write_flash 0x00000 wifi.bin
```

**选项 B：使用 Python 的 `esptool.py`**
直接在 CMD 中执行：
```bash
python -m esptool -p COM7 -b 115200 --before no_reset write_flash 0x00000 D:\wifi.bin
```
* *注：刷写完成后即可将跳线帽取下
---

### 🔍 参数详解

* **`-p COM7`**：指定连接的硬件端口。
* **`-b 115200`**：**必须用低速！** 软件透传无法承受 921600 等高速波特率，主控的软串口转发很容易丢包。
* **`--before no_reset`**：**核心灵魂参数。** 告诉电脑：“直接发数据，不要尝试重启 ESP32”。这样主控 ESP32 才会保持在透传模式，乖乖把数据转发给 ESP07s。
   * *(如果使用 PlatformIO，请点击左侧蚂蚁图标，运行 `Upload File System image` 任务)*。

> ⚠️ **初始启动与安全校验**
> 刷写完成后，主控板首次启动会建立一个名为 `OnStep` 的 Wi-Fi 热点（默认密码通常为 `password`）连接后，在浏览器输入 `192.168.0.1` 即可进入控制面板。
> **强烈建议：**在挂载昂贵的望远镜之前，务必进行空载测试！仔细验证 TMC5160 驱动器的电流设置、电机的运转方向，以及限位开关 (Limit Switches) 的触发状态，确保高扭矩谐波减速器不会对机械结构造成损坏。

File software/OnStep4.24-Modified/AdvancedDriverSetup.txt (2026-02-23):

// Advanced stepper driver mode setup  . . . . . . . . . . . . . . . . . . . . . . . . . . . . . . . . . . . . . . . . . .
// Use selections from this in your Config.h file's MOTION CONTROL section as detailed below
//
// M0, M1, M2, and M3 for Axis1/2 (RA/Azm) and are listed in Config.h's PINMAP matching Pins.xxx.h file.
// values (0b000 to 111): for example "#define ..STEP_CODE 4" is the same as "#define ..STEP_CODE 0b100" which sets M2 to HIGH, M1 to LOW, and M0 to LOW
//                                                                                                 / | \                  (1)         (0)            (0)
//                                                                                               M2  M1 M0
//

// Substitute the Axis# (1 to 5) for "n" in the examples below.

// * = Option is automatically set when AXISn_DRIVER_MODEL is specified, if using these don't specify _MODEL, _MICROSTEPS, or _MICROSTEPS_GOTO.
// ** = Option applies for Axis1 and Axis2 only.

#define AXISn_DRIVER_CODE_OFF             //   _OFF, n, Programs mode M0/M1/M2 as above. In SPI mode reg. value directly set. Option,*
#define AXISn_DRIVER_CODE_GOTO_OFF        //   _OFF, n, Programs mode as above, used during gotos.                            Option,*,**
                                          //         For Axis1 and Axis2 only.
#define AXISn_DRIVER_STEP_GOTO          1 //      1, n, (tracking mode steps/goto mode step.) Example: 32x to 8x goto = 4.    Adjust,*,**

// Settings for TMC2130, TMC5160, etc? stepper drivers when in SPI mode.
#define AXISn_DRIVER_INTPOL          true //   true, false to disable 256x interpolation.                                     Option
#define AXISn_DRIVER_IHOLD            OFF //    OFF, n, (mA.) Current during standstill. OFF uses IRUN/2.0                    Option
#define AXISn_DRIVER_IRUN             OFF //    OFF, n, (mA.) Current during tracking, appropriate for stepper/driver/etc.    Option
#define AXISn_DRIVER_IGOTO            OFF //    OFF, n, (mA.) Current during slews. OFF uses same as IRUN.                    Option,**
#define AXISn_DRIVER_PWM_GRAD         OFF //    OFF, n, (0 to 255.) See TMC2130 datasheet sect 6.3 or TMC5160/61 sect 7.4     Option,**
#define AXISn_DRIVER_FS_VHIGH         OFF //    OFF, n, (tracking mode steps/s.) Velocity switchover full step & slow decay.  Option,**
#define AXISn_DRIVER_SC_VHIGH         OFF //    OFF, n, (tracking mode steps/s.) Velocity switchover to spreadCycle mode.     Option,**
#define AXISn_DRIVER_RSENSE          0.13 //   0.13, n, Rsense for TMC2130, Rsense for SSS TMC5160 is 0.075, can vary.        Adjust,*

#define MODE_SWITCH_BEFORE_SLEW       OFF //    OFF, Applies mode settings during slew at 128uS/step speeds.                  Option,*
                                          //         ON Applies mode settings before/after the slew.
#define MODE_SWITCH_SLEEP             OFF //    OFF, ON. Mode switch before/after slew insert 3ms delay before drivers step.  Option,*

#define AXISn_DRIVER_DECAY_MODE       OFF //    OFF, HIGH, LOW, OPEN, SPREADCYCLE, STEALTHCHOP.                               Option,*
#define AXISn_DRIVER_DECAY_MODE_GOTO  OFF //    OFF, HIGH, LOW, OPEN, SPREADCYCLE, STEALTHCHOP.                               Option,*,**
                                          //         Decay mode control, applied before/after the slew.  DRV8825, TMC2209, 
                                          //         TMC2130, TMC5160, etc.  DRV8825 modules need modification to enable this.
                                          //         Axis1/2 decay mode pin locations, if available, are in Pins.xxx.h

#define AXISn_DRIVER_ENABLE           LOW //    LOW, HIGH state required on EN line to enable the S/D driver.                 Adjust

// . . . . . . . . . . . . . . . . . . . . . . . . . . . . . . . . . . . . . . . . . . . . . . . . . . . . . . . . . . . .

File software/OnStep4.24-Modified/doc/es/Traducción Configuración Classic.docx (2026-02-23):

CONFIGURACION OnStep CLASSIC (Mega 2560 ó Teensy3.x)
#defineClassic _OFF | Poner ON para usar esta configuración.

AJUSTES PARA CONFIGURAR LAS FUNCIONES DEL CONTROLADOR
#define ALIGN_GOTOASSIST_OFF | Habilita el asistente de Goto en modelos de monturas ecuatoriales

#define SERIAL1_BAUD_DEFAULT 9600 | Velocidad predeterminada para el puerto serie 1

#define MOUNT_TYPE_GEM | Tipo de montura _ GEM=ecuatorial alemana

| _FORK =horquilla apaga “Meridiam Flips” despúes de la alineación | Alineación 1,2 ó 3 estrellas
| _FORK_ALT =horquilla apaga “Meridiam Flips” después de la alineación | Alineación con 1 estrella
| _ALTAZM = tipo Dobson y otras altacimutales | Solo alineación 1 estrella
#define STRICT_PARKING_OFF | Aparcamiento estricto. Con _ON la salida del parking solo se produce si se estaciona con éxito.

#define ST4_OFF | ST4_ON Para habilitar interfaz. ST4 _PULLUP habilita interfaz y cualquier resisten pullup interna | Ver Pines para conexión

#define ST4_HAND_CONTROL_OFF | Diferentes modos de configurar interfaz ST4 | (ver versión original/inglés)

#define ST4_ALTERNATE_PINS_OFF | Otros pines alternativos | (ver version original/inglés)

#define SEPARATE_PULSE_GUIDE_RATE_ON | Velocidad de guiado y centrado distinta para que no se interfieran entre si | Por Defecto = ON

#define GUIDE_TIME_LIMIT O | Límite del tiempo de guiado en segundos. Por seguridad. | En segundos

#define RTC_OFF | Soporte para RTC (Reloj en tiempo real). RTC_DS3234 para interfaz DS3234 en pines interfaz SPI

#define PPS_SENSE_OFF | Use _ON ó _PULLUP habilita entrada y usa resistencia pullup incorporada. Fuente reloj opcional | Para GPS por ejemplo.

#define PEC_SENSE_OFF | Habilita si se usa sensor de PEC (ver en su caso pines, configuraciones, valores, etc..) | IGNORAR en Alt/Azm

#define PEC_SENSE_STATE HIGH | Define estado “alto” del PEC en el Pin 2

#define LIMIT_SENSE_OFF | Sensor de limite opcional (detiene gotos y seguimiento) Pin 3

#define STATUS_LED_PINS_OFF | LED indica que el controlador está activo. Con seguimiento parpadea repidamente Pin 9

#define STATUS_LED2_PINS_OFF | LED parpadea en intervalos de 1seg. Al sincronizar PPS. Ilumina débilmente buscador polar | Mismo pin (10) que SPI

#define RETICULE_LED_PINS_OFF | Establece el brillo predeterminado del LED en un rango n= 0 a 255 | STATUS_LED_PINS es _ON

#define BUZZER_OFF | Para si utilizamos Zumbador. Especificar frecuencia (ej. “BUZZER 2000”)o si es piezoeléctrico.

#define DEFAULT_SOUND_ON | Sonido al inicio.

#define TRACK_REFRACTION_RATE_DEFAULT_OFF | Ajuste opcional de la velocidad de seguimiento para compensar la refracción atmosférica

#define REMENBER_AUTO_MERIDIAN_FLIP_OFF | Para recordar por OnStep la última configuración automática del paso de meridiano

#define REMENBER_PAUSE_HOME_OFF | Para recorder la última pausa de inversión del meridiano en la configuración de inicio.

AJUSTES PARA ARMONIZAR LA MONTURA
#define REMENBER_MAX_RATE_OFF | Con _ON se recuerda los ratios establecidos en el controlador ASCOM o en aplicación ANDROID

#define MaxRate 96 | Número mínimo de microsegundos entre micro pasos. Más bajo implica un goto más rápido siendo 32 el mínimo aconsejable para Mega 2560. Más alto que 96 está bien.

#define DegreesForAcceleration 5.0 | Nº aproximado de grados para aceleración/desaceleración completa. Valores más altos implican acel./desacel. más prolongada. Más bajo puede implicar no terminen gotos con micropasos

#define DegreesForRapidStop 1.0 | Nº aproximado de grados necesarios para detener si se solicita o al exceder un límite la montura. Valores más bajos pueden hacer que los gotos nunca terminen si se habilita micropasos.

#defina BlasklashTakeupRate 25 | Tasa de respuesta al contragolpe (holgura mecánica de la montura). Demasido rápido paran los motores, demasiado lento y la montura será lenta mientes se mueve en blasklach

#define StepsPerDegreeAxis1 12800.0 | Calculado como : pasos motor * micropasos * tasas de reducción engranajes (1,2,…) / 360 | Axis1 es para RA/Az

#define StepsPerDegreeAxis2 12800.0 | Calculado como : pasos motor * micropasos * tasas de reducción engranajes (1,2,…) / 360 | Axis2 es para Dec/Alt

#defineStepsPerWormRotationAxis1 12800L | PEC nº pasos para una rotación completa del bisinfin | IGNORAR en Alt/Azm

#define PECBufferSize 824 | Tamaño del Buffer para PEC si es necesario. | IGNORAR en Alt/Azm

#define REVERSE_AXIS1_OFF | Invierte la dirección del movimiento eje RA/Azm

#define REVERSE _AXIS2_OFF | Invierte la dirección del movimiento eje Dec/Alt

#define MinutesPastMeridiamE 60 | Para gotos cuando pasen el meridiano. A veces se utiliza en monturas de horquilla para alinear | IGNORAR en Alt/Azm

#defineMinutesPastMeridiamW 60 | Como anterior si está en el lado Oeste. | IGNORAR en Alt/Azm

#define UnderPoleLimit 12 | Angulo horario máximo permitido (+/-) debajo del polo celeste | IGNORAR en Alt/Azm

#define MinDec -91 | Declinación mínima permitida -91=desactivado | IGNORAR en Alt/Azm

#define MaxDec +91 | Declinación máxima permitida 91= desactivado | IGNORAR en Alt/Azm

#define MaxAzm 180 | +/- máximo Azimut permitido, por defecto 180. Rango de 180 a 360 | SOLO en Alt/Azm

AJUSTES PARA LOS CONTROLADORES DE LOS MOTORES
#define AXIS1_DISABLED_HIGH #define AXIS2_DISABLED_HIGH | Opcional habilitar soporte “enable” del controlador. OnStep los pondrá HIGH. Por defecto desabilitados al inicio y cuando está estacionado. LOW desabilita los controladores.

#define AUTO_POWER_DOWN_AXIS2_OFF | Apaga eje declinación cuando no se usa . Durante el seguimiento permanece habilitado | SOLO ECUTORIALES

| En los comandos siguientes use valores de 0 a 7 para configurar M0/M1/M2 7=128X, 6=64X, 5=32X, 4=16X, 3=8X, 2=4X, 1=2X, 0=1X (DRV8825 o A4988 o RAPS128) Ej “#define_AXIS1_MODE 4” establece que M2 es ALTO, M1 es BAJO, M0 es BAJO
#define AXIS1_MODE_OFF | Programa el modo de micropasos en eje RA/Az (M0/M1/M2)

#define AXIS1_MODE_GOTO_OFF | Programa el modo de micropasos en eje RA/Az (M0/M1/M2) usados durante los gotos

#define AXIS1_STEP_GOTO 1 | 1=el modo goto es el mismo que el modo normal. Ej. Si modo seguimiento normal es 32x y el goto es 8x esto sería 4

#define AXIS2_MODE_OFF | Programa el modo de micropasos en eje Dec/Alt (M0/M1/M2)

#define AXIS2_MODE_GOTO_OF | Programa el modo de micropasos en eje Dec/Alt (M0/M1/M2 usado durante los gotos

#define AXIS2_STEP_GOTO 1 | 1=el modo goto es el mismo que el modo normal. Ej. Si modo seguimiento normal es 32x y el goto es 8x esto sería 4

#define MODE_SWITCH_BEFORE_SLEW_OFF | _ON para _MODE y _MODE GOTO. Ajustes para iniciar/detener justo antes/después del giro de lo contrario estarán activos durante el giro a <128uS/step

#define DECAY_MODE_OFF #define DECAY_MODE_GOTO_OFF | Control del decaimiento secundario del controlador-para ambos ejes-siempre se inician/detienen justos antes/después del giro- Opciones _HIGH,_LOW_OPEN defecto_OFF | MODE_SWITCH_BEFORE_SL EW debe ser OFF si se usa

#define MODE_SWITCH_SLEEP_OFF | Si el interruptor de modo disminución/micropaso ocurre antes/después de un giro, inserta un retrado de 3 mseg. Antes de que los motores den un paso.

#define AXIS1_FAULT_OFF #define AXIS2_FAULT_OFF | Detección de fallos del controlador de pasos. Otros ajustes son LOW y HIGH

ROTADOR DESROTADOR TELESCOPIOS ALT/AZ
#define ROTATOR_OFF | Rotador habilita/deshabilita la función (cualquier tipo montura).Desrotador solo ALT/AZ montura

#define MaxRateAxis3 8 | Es el mínimo número de milisegundos entre micropasos | Por defecto=8

#define StepsPerDegreeAxis3 64.0 | Calculado como : pasos motor * micropasos * tasas de reducción engranajes (1,2,…) / 360

#define REVERSE_AXIS3_OFF | Invierte la dirección del motor del rotador

#define MiniAxis3 -180 | Mínimo permitido del rotador

#define MaxAxis3 180 | Máximo permitido del rotador

ENFOCADOR 1
#define FOCUSER1_OFF | Activa/desactiva la función de enfoque

#define MaxRateAxis4 8 | Es el mínimo número de milisegundos entre micropasos | Por defecto=8

#define StepsPerMicrometerAxis4 0.5 | Resolver mediante pruebas u otros medios

#define REVERSE_AXIS4_OFF | Invierte la dirección de movimiento del enfocador.

#define MinAxis4 -25 | Posición mínima permitida en milímetros | Por defecto= -25

#define MaxAxis4 25 | Posición máxima permitida en milímetros | Por defecto = 25

ENFOCADOR 2
#define FOCUSER2_OFF | Activa/desactiva la función de enfoque

#define MaxRateAxis5 8 | Es el mínimo número de milisegundos entre micropasos | Por defecto=8

#define StepsPerMicrometerAxis5 0.5 | Resolver mediante pruebas u otros medios

#define REVERSE_AXIS5_OFF | Invierte la dirección de movimiento del enfocador.

#define MinAxis5 -25 | Posición mínima permitida en milímetros | Por defecto= -25

#define MaxAxis5 25 | Posición máxima permitida en milímetros | Por defecto = 25

#include “Pins.Classic.h”

#endif

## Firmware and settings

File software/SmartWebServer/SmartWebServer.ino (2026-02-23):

/*
 * 标题       OnStep Smart Web Server (智能网页服务器)
 * 作者       Howard Dutton
 *
 * 版权所有 (C) 2016 至 2024 Howard Dutton
 *
 * 本程序为自由软件：您可以根据自由软件基金会发布的 GNU 通用公共许可证（GNU GPL）
 * 的条款重新分发和/或修改它，无论是许可证的第 3 版，还是（由您选择）任何更高版本。
 *
 * 本程序的发布是希望它能有用，但【没有任何担保】；
 * 甚至没有对【适销性】或【特定用途适用性】的暗示性担保。
 * 有关更多详细信息，请参阅 GNU 通用公共许可证。
 *
 * 您应该随本程序一起收到了一份 GNU 通用公共许可证的副本。
 * 如果没有，请参阅 <http://www.gnu.org/licenses/>。
 *
 * 修订历史：请参阅 GitHub
 *
 * 作者: Howard Dutton
 * http://www.stellarjourney.com
 * hjd1964@gmail.com
 *
 * 描述
 *
 * 用于 OnStep 和 OnStepX 的网页和 IP 服务器
 *
 */

#define Product "Smart Web Server"
#define FirmwareVersionMajor  "2"
#define FirmwareVersionMinor  "08"
#define FirmwareVersionPatch  "l"

// 请使用 Config.h 根据您的要求配置 SWS (智能网页服务器)

#include "src/Common.h"
NVS nv; // 非易失性存储 (EEPROM替代品)
#include "src/lib/tasks/OnTask.h"
#include "src/libApp/cmd/Cmd.h"
#include "src/libApp/bleGamepad/BleGamepad.h"
#include "src/libApp/encoders/Encoders.h"
#include "src/pages/Pages.h"
#include "src/libApp/status/Status.h"

#include "src/lib/ethernet/cmdServer/CmdServer.h"
#include "src/lib/ethernet/webServer/WebServer.h"
#include "src/lib/wifi/cmdServer/CmdServer.h"
#include "src/lib/wifi/webServer/WebServer.h"

#if DEBUG == PROFILER
  extern void profiler();
#endif

#if COMMAND_SERVER == PERSISTENT || COMMAND_SERVER == BOTH
  // 持久连接命令服务器 (通常用于 Planetarium 软件)
  CmdServer persistentCmdSvr1(9996, 10L*1000L, true);
  #if OPERATIONAL_MODE != ETHERNET_W5100
    CmdServer persistentCmdSvr2(9997, 10L*1000L, true);
  #endif
  CmdServer persistentCmdSvr3(9998, 10L*1000L, true);
#endif

#if COMMAND_SERVER == STANDARD || COMMAND_SERVER == BOTH
  // 标准命令服务器 (通常用于 App，端口 9999)
  CmdServer cmdSvr(9999, 1L*1000L);
#endif

void systemServices() {
  nv.poll(); // 轮询存储服务
}

void pollWebSvr() {
  www.handleClient(); // 处理网页客户端请求
}

void pollCmdSvr() {
  #if COMMAND_SERVER == PERSISTENT || COMMAND_SERVER == BOTH
    persistentCmdSvr1.handleClient(); Y; // Y 是 yield() 的宏，让出 CPU 时间
    #if OPERATIONAL_MODE != ETHERNET_W5100
      persistentCmdSvr2.handleClient(); Y;
    #endif
    persistentCmdSvr3.handleClient(); Y;
  #endif

  #if COMMAND_SERVER == STANDARD || COMMAND_SERVER == BOTH
    cmdSvr.handleClient();
    Y;
  #endif
}

void setup(void) {
  #if OPERATIONAL_MODE == WIFI
    WiFi.disconnect();
    WiFi.softAPdisconnect(true); // 断开之前的 WiFi 连接，重置状态
  #endif

  strcpy(firmwareVersion.str, FirmwareVersionMajor "." FirmwareVersionMinor FirmwareVersionPatch);

  // 启动调试串口 (如果开启了调试模式)
  if (DEBUG == ON || DEBUG == VERBOSE || DEBUG == PROFILER) SERIAL_DEBUG.begin(SERIAL_DEBUG_BAUD);
  delay(2000);

  #ifdef PIN_INIT
    PIN_INIT();
  #endif

  VF("MSG: SmartWebServer "); VL(firmwareVersion.str);
  VF("MSG: MCU = "); VF(MCU_STR); V(", ");
  VF("Pinmap = "); VLF(PINMAP_STR); // 打印引脚映射信息

  delay(2000);

  // 调用蓝牙手柄初始化
  #if (BLE_GAMEPAD == ON && ESP32)
    VLF("MSG: Init BLE");
    bleInit();
  #endif

  // 调用硬件特定初始化 (HAL)
  VLF("MSG: Init HAL");
  HAL_INIT();
  HAL_NV_INIT();
  #if LED_STATUS != OFF
    pinMode(LED_STATUS_PIN, OUTPUT);
  #endif

  // 尝试连接 OnStep 主控
  int serialSwap = OFF;
  serialSwap = SERIAL_SWAP;
  if (serialSwap == AUTO) serialSwap = AUTO_OFF;

  long serial_baud = SERIAL_BAUD;
  onStep.serialBegin(SERIAL_BAUD_DEFAULT, serialSwap); // 以默认波特率启动串口
  uint8_t tb = 1;
Again:
  VLF("MSG: Clearing serial channel");
  onStep.clearSerialChannel();

  // 寻找 OnStep 信号
  VLF("MSG: Attempting to contact OnStep");
  SERIAL_ONSTEP.print(":GVP#"); delay(100); // 发送查询产品命令
  String s = SERIAL_ONSTEP.readString();
  if (s == "On-Step#") {
    // 如果配置了不止一种波特率 (也就是想要高速通讯)
    if (SERIAL_BAUD != SERIAL_BAUD_DEFAULT) {
      // 获取 OnStep 支持的最快波特率，Mega2560 推荐返回 '4' 代表 19200
      SERIAL_ONSTEP.print(":GB#");
      delay(100);
      if (SERIAL_ONSTEP.available() != 1) { onStep.serialRecvFlush(); goto Again; }
      if (SERIAL_ONSTEP.read() == '4' && serial_baud > 19200) serial_baud = 19200;
      // 设置更快的波特率
      SERIAL_ONSTEP.print(onStep.highSpeedCommsStr(serial_baud)); delay(100);
      if (SERIAL_ONSTEP.available() != 1) { onStep.serialRecvFlush(); goto Again;
      }
      if (SERIAL_ONSTEP.read() != '1') goto Again;
    }

    // 一切就绪，只需更改本地波特率以匹配 OnStep
    onStep.serialBegin(serial_baud, serialSwap);
    #if DEBUG == REMOTE
      debugRemoteConnected = true;
    #endif
    
    VLF("MSG: OnStep Connection established"); // 连接建立成功
  } else {
    if (DEBUG == ON || DEBUG == VERBOSE) { VF("MSG: No valid reply found ("); V(s); VL(")");
    }
    #if LED_STATUS == ON
      digitalWrite(LED_STATUS_PIN, LED_STATUS_OFF_STATE);
    #endif
    // 没有收到有效回复，尝试切换波特率和/或交换串口引脚 (Swap)
    onStep.serialRecvFlush();
    tb++;
    // 循环尝试不同的组合：默认/交换引脚，默认/高速波特率
    if (tb == 16) { tb = 1; if (serialSwap == AUTO_OFF) serialSwap = AUTO_ON;
    else if (serialSwap == AUTO_ON) serialSwap = AUTO_OFF; }
    if (tb == 1) onStep.serialBegin(SERIAL_BAUD_DEFAULT, serialSwap);
    if (tb == 6) onStep.serialBegin(serial_baud, serialSwap);
    if (tb == 11) { if (SERIAL_BAUD_DEFAULT == 9600) { onStep.serialBegin(19200, serialSwap);
    } else tb = 15; }
    goto Again; // 重试
  }
  onStep.clearSerialChannel();
  // 系统服务
  // 添加系统服务任务，每 10ms 运行一次，因此写入 1KB NV 数据大约需要 10 秒
  VF("MSG: Setup, starting system services");
  VF(" task (rate 10ms priority 7)... ");
  if (tasks.add(10, 0, true, 7, systemServices, "SysSvcs")) { VL("success"); } else { VL("FAILED!");
  }

  // 准备 NV (非易失性存储)
  if (!nv.isKeyValid(INIT_NV_KEY)) {
    VF("MSG: NV, invalid key wipe "); V(nv.size);
    VLF(" bytes");
    if (nv.verify()) { VLF("MSG: NV, ready for reset to defaults");
    }
  } else { VLF("MSG: NV, correct key found");
  }

  // 获取命令和网页超时设置
  if (!nv.hasValidKey()) {
    nv.write(NV_TIMEOUT_CMD, (int16_t)cmdTimeout);
    nv.write(NV_TIMEOUT_WEB, (int16_t)webTimeout);
  }
  cmdTimeout = nv.readUI(NV_TIMEOUT_CMD);
  webTimeout = nv.readUI(NV_TIMEOUT_WEB);

  // 启动网络服务器 (WiFi 或 以太网)
  #if OPERATIONAL_MODE == WIFI
    VLF("MSG: Init WiFi");
    wifiManager.init();
  #else
    VLF("MSG: Init Ethernet");
    ethernetManager.init();
  #endif

  // 准备编码器
  VLF("MSG: Initialize Encoders");
  encoders.init();
  // 初始化完成，必要时写入 NV 密钥
  if (!nv.hasValidKey()) {
    nv.writeKey((uint32_t)INIT_NV_KEY);
    nv.wait();
    if (!nv.isKeyValid(INIT_NV_KEY)) { DLF("ERR: NV, failed to read back key!"); } else { VLF("MSG: NV, reset complete");
    }
  }

  VLF("MSG: Set webpage handlers"); // 设置网页路由处理程序
  www.on("/index.htm", handleRoot);
  www.on("/index-ajax-get.txt", indexAjaxGet);
  www.on("/index.txt", indexAjax);

  www.on("/mount.htm", handleMount);
  www.on("/mount-ajax-get.txt", mountAjaxGet);
  www.on("/mount-ajax.txt", mountAjax);
  www.on("/libraryHelp.htm", handleLibraryHelp);

  www.on("/rotator.htm", handleRotator);
  www.on("/rotator-ajax-get.txt", rotatorAjaxGet);
  www.on("/rotator-ajax.txt", rotatorAjax);

  www.on("/focuser.htm", handleFocuser);
  www.on("/focuser-ajax-get.txt", focuserAjaxGet);
  www.on("/focuser-ajax.txt", focuserAjax);

  www.on("/auxiliary.htm", handleAux);
  www.on("/auxiliary-ajax-get.txt", auxAjaxGet);
  www.on("/auxiliary-ajax.txt", auxAjax);
  #if ENCODERS == ON
    www.on("/enc.htm", handleEncoders);
    www.on("/enc-ajax-get.txt", encAjaxGet);
    www.on("/enc-ajax.txt", encAjax);
  #endif

  www.on("/net.htm", handleNetwork);

  www.on("/", handleRoot);
  
  www.onNotFound(handleNotFound);
  #if COMMAND_SERVER == PERSISTENT || COMMAND_SERVER == BOTH
    #if OPERATIONAL_MODE != ETHERNET_W5100
      VLF("MSG: Starting port 9996 cmd server");
      persistentCmdSvr3.begin();
      VLF("MSG: Starting port 9997 cmd server");
      persistentCmdSvr2.begin();
    #endif
    VLF("MSG: Starting port 9998 cmd server");
    persistentCmdSvr1.begin();
  #endif

  #if COMMAND_SERVER == STANDARD || COMMAND_SERVER == BOTH
    VLF("MSG: Starting port 9999 cmd server");
    cmdSvr.begin();
  #endif

  VLF("MSG: Starting port 80 web server");
  www.begin();

  // 留出时间让后台服务器启动
  delay(2000);
  // 最后一次清空串口通道
  onStep.clearSerialChannel();

  if (status.onStepFound) {
    status.update();
    delay(100);
  }

  state.init();

  VF("MSG: Setup, starting cmd channel polling"); // 启动命令通道轮询
  VF(" task (rate 5ms priority 2)... ");
  if (tasks.add(5, 0, true, 2, pollCmdSvr, "cmdPoll")) { VL("success"); } else { VL("FAILED!");
  }

  VF("MSG: Setup, starting web server polling"); // 启动网页服务器轮询
  VF(" task (rate 20ms priority 3)... ");
  if (tasks.add(20, 0, true, 3, pollWebSvr, "webPoll")) { VL("success"); } else { VL("FAILED!");
  }

  // 启动任务管理器调试事件
  #if DEBUG == PROFILER
    tasks.add(142, 0, true, 7, profiler, "Profilr");
  #endif

  #if (BLE_GAMEPAD == ON && ESP32)
    bleSetup();
  #endif

  VLF("MSG: SmartWebServer ready");
}

void loop(void) {
  #if (BLE_GAMEPAD == ON && ESP32)
    bleTimers(); Y;
    bleConnTest(); Y;
  #endif

  tasks.yield(); // 任务调度器让步
}

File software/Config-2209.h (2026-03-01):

// ---------------------------------------------------------------------------------------------------------------------------------
// Configuration for OnStep

/*
 *          For more information on setting OnStep up see http://www.stellarjourney.com/index.php?r=site/equipment_onstep 
 *                      and join the OnStep Groups.io at https://groups.io/g/onstep
 * 
 *           *** Read the compiler warnings and errors, they are there to help guard against invalid configurations ***
*/

// ---------------------------------------------------------------------------------------------------------------------------------
// ADJUST THE FOLLOWING TO CONFIGURE YOUR CONTROLLER FEATURES ----------------------------------------------------------------------
// <-Req'd = always must set, <-Often = usually must set, Option = optional, Adjust = adjust as req'd, Infreq = infrequently changed

// 引脚映射(PINMAP) ------------------------------------------------- see https://onstep.groups.io/g/main/wiki/Configuration-Controller#PINMAP
//   *** See the matching Pins.xxx.h file for your setup (found by looking in src/pinmaps/Models.h) with detailed information ***
//   *** to be sure it matches your wiring.            *** USE AT YOUR OWN RISK ***                                           ***

// 参数名(Parameter Name)              Value   Default  Notes                                                                      Hint
#define PINMAP                    MaxESP3 //    OFF, Choose from: MksGenL2, MiniPCB2, MaxPCB2, MaxESP3, CNC3, STM32Blue,     <-Req'd
                                          //    关闭，从以下选项中选择：MksGenL2、MiniPCB2、MaxPCB2、MaxESP3、CNC3、STM32蓝色，<-需要
                                          //    MaxSTM3, FYSETC_S6_2, etc.  其他主板和更多信息，在Constants.h

// 串口通信通道(SERIAL PORT COMMAND CHANNELS) --------------------------- see https://onstep.groups.io/g/main/wiki/Configuration-Controller#SERIAL
#define SERIAL_A_BAUD_DEFAULT        9600 //   9600, n. Where n=9600,19200,57600,115200 (common baud rates.)                  Infreq
                                          //   9600，n.其中n=9600，19200，57600，115200（常见波特率）
#define SERIAL_B_BAUD_DEFAULT        9600 //   9600, n. See (src/HAL/) for your MCU Serial port # etc.                        Option
                                          //   9600, n. 查看 (src/HAL/) 确认你的MCU串口号等信息
#define SERIAL_B_ESP_FLASHING         ON  //    OFF, ON Upload ESP8266 WiFi firmware through SERIAL_B with :ESPFLASH# cmd.    Option
                                          //    OFF, ON 通过串口B给ESP8266 WiFi模块刷固件（使用 :ESPFLASH# 命令）
#define SERIAL_C_BAUD_DEFAULT         ON  //    OFF, n, ON for ESP32 Bluetooth.                                               Option
                                          //    OFF, n, 如果是ESP32蓝牙则设为ON
#define SERIAL_C_BLUETOOTH_NAME  "OnStep" // "On..", Bluetooth device name for ESP32.                                         Option
                                          //  ESP32的蓝牙设备名称

// 赤道仪类型(MOUNT TYPE) ----------------------------------------- see https://onstep.groups.io/g/main/wiki/Configuration-Controller#MOUNT_TYPE
#define MOUNT_TYPE                    GEM //    GEM, GEM for German Equatorial, FORK for Equatorial Fork, or ALTAZM          <-Req'd
                                          //    GEM, GEM=德式赤道仪, FORK=叉式赤道仪, ALTAZM=经纬仪
                                          //    Dobsonian etc. mounts. GEM Eq mounts perform meridian flips.
                                          //    Dobsonian (道布森) 等也算经纬仪, 注意：只有 GEM 模式会执行中天翻转

// 用户反馈(USER FEEDBACK) ----------------------------------- see https://onstep.groups.io/g/main/wiki/Configuration-Controller#USER_FEEDBACK
#define LED_STATUS                     ON //     ON, Blinks w/sidereal tracking otherwise steady on indicates activity.       Option
                                          //     ON, 恒星速跟踪时闪烁，常亮表示有其他活动（如GOTO）
#define LED_STATUS2                   OFF //    OFF, ON Blinks 1s interval w/PPS sync, steady for gotos, off if in standby.   Option
                                          //    OFF, ON 收到PPS同步信号闪烁1秒，GOTO时常亮，待机时灭
#define LED_RETICLE                   OFF //    OFF, n. Where n=0..255 (0..100%) activates feature sets default brightness.   Option
                                          //    OFF, n. n=0..255 (0..100%) 开启极轴镜照明功能并设置默认亮度
#define BUZZER                        OFF //    OFF, ON, n. Where n=100..6000 (Hz freq.) for piezo speaker. ON for buzzer.    Option
                                          //    OFF, ON, n. n=100..6000 (Hz频率) 适用于压电喇叭。如果是普通有源蜂鸣器填ON
#define BUZZER_STATE_DEFAULT          OFF //    OFF, ON Start with piezo buzzer/speaker enabled.                              Option
                                          //    OFF, ON 启动时默认开启蜂鸣器/喇叭声音
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

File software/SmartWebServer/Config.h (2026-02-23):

// ---------------------------------------------------------------------------------------------------------------------------------
// OnStep 智能网页服务器扩展模块 (SmartWebServer Add-on) 配置

/*
 * 有关设置此扩展模块的更多信息，请参阅 https://onstep.groups.io/g/main/wiki/7119 
 * 并加入 OnStep Groups.io 讨论组 https://groups.io/g/onstep
 * * *** 请务必阅读编译器的警告和错误信息，它们能帮你防止配置错误 ***
*/

// ---------------------------------------------------------------------------------------------------------------------------------
// 调整以下内容以配置您的扩展模块功能 ------------------------------------------------------------------------
// <-Req'd = 必须设置, <-Often = 通常需要设置, Option = 可选, Adjust = 按需调整, Infreq = 极少更改

// 若 WiFi 启动成功，将出现一个默认 SSID 为 "ONSTEP" 且默认密码为 "password" 的热点。
// 连接后，网页管理地址是 "192.168.0.1"，命令通道地址是 "192.168.0.1:9996 到 9999"。
// 如果被锁死无法连接，在再次上传/烧录之前，从 Arduino IDE 的 "工具" (Tools) 菜单中选择 
// "Erase Flash: All Flash Contents" (擦除所有 Flash 内容) 可以帮助恢复对 ESP8266 或 ESP32 的访问；e:\模型\谐波赤道仪\Onstep\OnStep\SmartWebServer\src\locales\Locale.h
// 或者查看 Extended.config.h 以清除 NV (非易失性存储)。

//      参数名                        值       默认值    注释                                                                       提示
// 运行模式 (OPERATIONAL MODE) ----------------------------------------------------------------------------------------------------------------
#define OPERATIONAL_MODE             WIFI //   WIFI, 或者使用 ETHERNET_W5100 或 ETHERNET_W5500 (有线网模块)                  <-必须设置

// 串口设置 (SERIAL PORTS) --------------------------------------------------------------------------------------------------------------------
#define SERIAL_BAUD_DEFAULT          9600 //   9600, 此参数的常用波特率为 9600, 19200, 57600, 115200 等。                      极少改
                                          //         与其连接的 OnStep 串口必须使用与上面相同的速率。
#define SERIAL_BAUD                115200 // 115200, 或者使用 19200, 57600, 115200, 230400, 460800 (并非所有设备都支持 > 115200)
                                          //         (OnStep 和这里都要改。) 如果与 Mega2560 版 OnStep 通信，自动使用 19200。
#define SERIAL_SWAP                  AUTO //   AUTO, 自动检查两者。ON 为交换端口 (Swapped)，OFF 为仅使用默认端口。             极少改
                                          //         此选项在 ETHERNET (以太网) 模式下被忽略。

// 状态指示灯 (STATUS LED) ----------------------------------------------------------------------------------------------------------------------
#define LED_STATUS                     ON //     ON, 启用 LED，连接过程中闪烁，连接成功后常亮。                                极少改
#define LED_STATUS_ON_STATE          HIGH //   HIGH, LED 点亮时的电平状态 (HIGH 或 LOW)。

// 显示设置 (DISPLAY - 网页界面) -------------------------------------------------------------------------------------------------------------------------
#define DISPLAY_LANGUAGE             L_cn //   L_en, 英语。或者 L_ce, L_de, L_en, L_us, L_es (两字母国家代码)。                按需
#define DISPLAY_WEATHER               OFF //    OFF, ON 以本地默认单位显示环境状况 (需传感器)。                               可选
#define DISPLAY_INTERNAL_TEMPERATURE   ON //    OFF, ON 以本地默认单位显示 MCU 内部温度。                                     可选
#define DISPLAY_WIFI_SIGNAL_STRENGTH   ON //     ON, 通过 Web 界面报告无线信号强度。OFF 则不显示。                              可选
#define DISPLAY_RESET_CONTROLS        OFF //    OFF, ON 允许复位 (如果支持)，FWU 用于 STM32 固件上传引脚置高。                可选

#define DISPLAY_SERVO_MONITOR         OFF //    OFF, ON 显示 OnStepX 的伺服电机监视器 (任意轴)。                              可选
#define DISPLAY_SERVO_ORIGIN_CONTROLS OFF //    OFF, ON 显示用于设置伺服绝对编码器原点的控制选项。                            可选

// 编码器支持 (ENCODER SUPPORT) -----------------------------------------------------------------------------------------------------------------
// 以下部分设置在首次上传时作为默认值存储在 NV (EEPROM) 中。除非擦除 NV 
// 或配置为运行时恢复默认值，否则以后对下面的更改可能会被忽略。
#define ENC_AUTO_SYNC_DEFAULT          ON //     ON, 自动将编码器位置同步给 OnStep。                                          可选
#define ENC_AUTO_SYNC_MEMORY          OFF //    OFF, ON 掉电保存“自动同步”的设置。                                            可选
#define ENC_SYNC_DURING_GOTO           ON //    OFF, ON 高分辨率编码器即使在 GOTO (高速转向) 期间也能修正指向。               可选

#define AXIS1_ENCODER                 OFF //    OFF, AB, AB_ESP32, CW_CCW, PULSE_DIR, AS37_H39B_B. 赤经/方位轴 (A/MA) & (B/SLO.) 可选
#define AXIS1_ENCODER_TICKS_DEG  22.22222 // 22.222, n, (ticks/degree.) 每度编码器脉冲数 (步数)。                             按需
#define AXIS1_ENCODER_REVERSE         OFF //    OFF, ON 反转计数方向。                                                        可选
#define AXIS1_ENCODER_DIFF_LIMIT_TO   300 //    300, n, (角秒) 编码器同步 *到* OnStep 时的最小差异阈值 (小于此值不更正)。     按需
#define AXIS1_ENCODER_DIFF_LIMIT_FROM OFF //    OFF, n, (角秒) 从 OnStep 同步 *回* 编码器时的最大差异阈值。                   按需
                                          //         用于绝对编码器。
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

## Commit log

2025-11-16 Update and rename DEC法兰盘.STEP to DEC法兰盘.STEP
    [DEC法兰盘.STEP]
2026-02-23 上传pcb实拍
2026-02-23 创建文件夹
2026-03-01 upadted BOM and PCB files
    [MechanicalBOM.xlsx]
